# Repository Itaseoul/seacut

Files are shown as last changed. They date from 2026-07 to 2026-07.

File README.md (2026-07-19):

# SEA:CUT Drifter / Friendly Floatee

Open-source, non-profit river-to-sea litter drifter. A low-cost GPS + cellular float you release into a river, track from anywhere, and recover. It maps how floating trash travels from source to sea, so communities know where to place booms and cleanups.

Built by 사단법인 이타서울 / GAA and contributors. Inspired by the open-hardware movement (Precious Plastic, RepRap, OpenMetBuoy).

License: firmware MIT · hardware CERN-OHL-S (reciprocal) · docs CC BY-SA 4.0 (ShareAlike) · **data CC BY 4.0** (permissive, so pooled observations combine and cite freely). Design/doc improvements stay open; data stays freely reusable. See [LICENSE-docs.md](LICENSE-docs.md). OSHWA certification: planned.

한국어는 아래 [한국어](#한국어) 참조.

---

## What it does

Wake on a timer, get a GPS fix, POST one small JSON ping over the cellular network, sleep. The device sends a single coordinate; a server assembles the track. No user-built gateway is required, the mobile network is the infrastructure.

```
[drifter] --GPS fix--> --cellular (LTE) POST--> [ingest server] --> [public map / open data]
   sleep <-------------------------------------------- 200 OK
```

This is cellular (LTE), not satellite. Coverage is river, estuary, and near-coast where mobile networks reach. Open-sea tracking would need a separate satellite backhaul and is out of scope for this build.

### Where this fits (and what it is not)

This is the **upstream measurement layer**, not an interceptor. It does not remove trash and makes no ocean-scale claim. Big open-ocean interception projects (e.g. The Ocean Cleanup) act at the mouth and in the gyres; this drifter works **before** that — at the sub-river, source side — to answer *where does floating litter actually concentrate, and where should a boom or a cleanup go?* It is complementary to those projects, not a replacement for them. Its output is an **effort/path signal and a citable trajectory**, not a pollution flux, total, or a learned-AI prediction. Treat every buoyancy, power, and drift number here as an **estimate until bench + field measurement**; this repo is a reference design, and field validation plus a DOI-deposited dataset are pending. The shortest honest path from blueprint to validated project — bench gates, one small release, a citable deposit — is [docs/VALIDATION_CAMPAIGN.md](docs/VALIDATION_CAMPAIGN.md).

## The four rules (they travel with the design)

Open-source hardware spreads on a few strong universal rules plus local adaptation, not on the absence of caveats.

1. Recover what you release. A device left in the water is the very problem we fight. Design for recovery, track it, go get it.
2. Safe power, no toxics. Protected Li-ion, no charging below 0 C or cooking above 45 C, contain a cell failure, non-metallic housing.
3. Do no harm to the water or its users. Smooth non-entangling shapes, avoid protected areas and seasons, tell nearby water users.
4. Own your deployment, follow your local rules. See [docs/DEPLOY_responsibly.md](docs/DEPLOY_responsibly.md).

## Choose your tier

| | Tier 0 Phone-in-a-Bottle | Tier 1 Cellular Bottle (default) | Tier 2 Reusable Robust |
|---|---|---|---|
| Brain | reused smartphone + GPSLogger | ESP32 cellular board | ESP32 cellular board |
| Housing | upcycled PET bottle + dry bag | upcycled PET bottle | bolt-sealed IP case |
| Approx cost | USD 5–35 | USD 50–70 | USD 90–130 |
| Best for | first pipeline test, any budget | the default upcycled float | long / cold / repeated campaigns |

Full parts list: [hardware/BOM.md](hardware/BOM.md). Reference board is the LILYGO T-A7670G R2 with onboard L76K GNSS (cellular LTE Cat.1 bis + separate GPS chip). Pick the A7670 band variant for your region.

**Tier 1.5 (solar-assisted, long-dwell estuary)** — wrap-around thin-film cells extend reporting life for units that linger in-coverage for weeks; no extra printed part. ★Solar extends power, not coverage (open sea still needs satellite). See [hardware/TIER1_5_SOLAR_DRIFTER.md](hardware/TIER1_5_SOLAR_DRIFTER.md).

## 3D printed parts (parametric, OpenSCAD)

The housing is an upcycled bottle, so only three small printed inserts are needed. Sources are parametric OpenSCAD, so you measure your own bottle and edit one file.

- `hardware/cad/electronics_bracket.scad` holds the board and cell, self-locating in the bottle
- `hardware/cad/ballast_keel.scad` carries lead-free weight low for self-righting
- `hardware/cad/recovery_loop.scad` a smooth closed loop for pole/net recovery

Each ships as `.scad` (editable source) and `.stl` (print + GitHub renders it in 3D); export `.3mf` for slicers. (OpenSCAD is mesh-based, so no true STEP — see [hardware/cad/README.md](hardware/cad/README.md); the foam template exports `.dxf`.) Preview: `hardware/cad/assembly.png`.

## Firmware

[firmware/](firmware/) — ESP32 + A7670 + L76K, single ping per wake. Library lewisxhe/TinyGSM-fork + TinyGPSPlus. Default 30-minute interval.

## Data

[data/schema.md](data/schema.md) — ping and track schema (FF-ID v1.1), CC BY. Run your own ingest server or POST to the shared community map. Standards interop: [docs/DATA_STANDARDS_CROSSWALK.md](docs/DATA_STANDARDS_CROSSWALK.md) maps FF-ID onto CF-NetCDF (trajectory), OGC SensorThings, and EMODnet Physics — a drifter track is a trajectory, **not** a GBIF/Darwin Core occurrence — with a zero-dependency exporter ([data/export_standards.py](data/export_standards.py)).

## Contribute

Build a unit, release and recover it in your river, POST trajectories, add your river and your locale notes. Fork, improve, translate. Open a pull request.

---

## 한국어

하천에서 바다로 가는 쓰레기의 길목을 재는 오픈소스 비영리 드리프터. 강에 띄우고 어디서나 추적하다 회수하는 저비용 GPS + 셀룰러 부유체다. 인증받은 완제품을 배포하지 않는다. 당신이 만들고, 배포를 당신이 책임지고, 지역 규정을 따른다.

동작: 타이머로 깨어나 GPS fix, 셀룰러(LTE)로 ping 하나 POST, 잔다. 서버가 궤적을 조립한다. 게이트웨이 불필요. 이 스택은 셀룰러이지 위성이 아니다. 커버 범위는 이동통신망이 닿는 하천·하구·근연안이다.

네 가지 규칙: (1) 회수한다 (2) 안전 전원·무독성 (3) 물·이용자·야생동물 무해 (4) 네 배포는 네가 책임·지역 규정 확인. 상세 [docs/DEPLOY_responsibly.md](docs/DEPLOY_responsibly.md).

티어: Tier 0 폰+페트병(USD 5–35) / Tier 1 셀룰러+페트병(USD 50–70, 기본) / Tier 2 재사용 견고(USD 90–130). 부품표 [hardware/BOM.md](hardware/BOM.md). 기준 보드 LILYGO T-A7670G R2(온보드 L76K).

3D: 하우징이 폐페트병이라 프린트 부품은 3개(브래킷·밸러스트 킬·회수 고리)뿐. 파라메트릭 OpenSCAD라 병 규격만 바꾸면 된다. 전력·신뢰성 상세는 [hardware/ELECTRONICS_POWER.md](hardware/ELECTRONICS_POWER.md)·[hardware/RELIABILITY.md](hardware/RELIABILITY.md). 이 리포는 레퍼런스 설계이며 현장 검증(대량 방류 실증)은 준비 중이다.

전체 글로벌 가이드: [docs/OPEN_HARDWARE_BOM_global_ko.md](docs/OPEN_HARDWARE_BOM_global_ko.md).

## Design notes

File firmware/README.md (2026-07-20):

# Firmware

ESP32 + A7670 (LTE Cat.1 bis) + L76K GNSS. **FF-ID schema v1.1** ([data/schema.md](../data/schema.md)).

Wake on a timer → **GPS fix first** (so an observation is kept even with no coverage) → append to an RTC store-and-forward buffer with a monotonic `seq` → modem on → network → POST buffered records oldest-first → deep sleep. The device sends points; the server assembles the track and never trusts arrival order (it orders by `ts_fix`/`seq`).

Reference firmware: [`drifter_a7670_cat1/drifter_a7670_cat1.ino`](drifter_a7670_cat1/drifter_a7670_cat1.ino) (MIT).

## v1.1 payload (what each ping carries)

```json
{"device_id":"ff-kr-bs-u0001","site_id":"nakdong-hakjang","seq":1487,
 "lat":35.105600,"lon":128.943100,"batt":4.02,
 "sample_interval_s":1800,"fix_quality":1.4,"gnss_source":"l76k",
 "ts_fix":"2026-07-10T09:00:00Z","ts":"2026-07-10T09:00:00Z"}
```

- `seq` — monotonic per-device counter. Survives deep sleep (RTC memory) **and** power loss (NVS). The server dedups and detects gaps by `seq`.
- `ts_fix` — the GPS UTC time of the fix (the observation time). Legacy `ts` is sent with the same value for older ingest servers (schema 1.0→1.1 mapping).
- `sample_interval_s` — declared nominal cadence (required by the schema for mixed-cadence weighting).
- `fix_quality` — HDOP from the L76K (omitted when invalid); `gnss_source:"l76k"`.
- **Store-and-forward**: up to 16 records buffer in RTC memory across sleep cycles; a cellular dead zone does not lose observations. Power loss drops the buffer (documented tradeoff) but never reuses a `seq`.

## Toolchain

- Arduino IDE, ESP32 Arduino core 3.0.x, board "ESP32 Dev Module"
- Libraries: **lewisxhe/TinyGSM-fork** (required; stock TinyGSM lacks the A7670 macro — uninstall stock), TinyGPSPlus, ArduinoHttpClient. `Preferences` ships with the core.

## Configure

- `DEVICE_ID` — pair it with the unit metadata directory `unit_id` (schema §3).
- `APN` for your SIM (Soracom `soracom.io` user/pass `sora`; 1NCE `iot.1nce.net`; KT MVNO `lte.ktfwing.com`; SKT MVNO `lte.sktelecom.com`). Global IoT SIMs roam on KT/SKT only — no LG U+.
- `SERVER_HOST` / `SERVER_PATH` — bench with the bundled `ingest_server.py` (`BENCH_HTTP 1`), then promote to HTTPS (`BENCH_HTTP 0`).
- `SLEEP_MINUTES` — see [hardware/ELECTRONICS_POWER.md](../hardware/ELECTRONICS_POWER.md) for the honest endurance table (all figures estimates pending bench measurement).

## Gotchas

- GPS is the separate L76K chip on its own UART (NMEA via TinyGPSPlus), not the modem's AT GNSS.
- Test with the 18650 installed. USB-only power browns out on the ~2 A transmit peak and looks like a modem fault.
- The v1.1 flow order (GPS → modem) differs from the original bench-validated v1.0 order (modem → GPS). Primitives are unchanged, but **re-run the bench sequence before deploying a fleet** (honesty: no improvement claims before measurement).
- Start with plain HTTP, promote to HTTPS after the pipeline works end to end.

## Security & supply chain

Two hard requirements before any **real** deployment. Both are honest gaps in the reference build today — documented here rather than silently assumed fixed.

**1. TLS is encrypted but not yet authenticated.** In production mode (`BENCH_HTTP 0`) the firmware POSTs over HTTPS/443 with `TinyGsmClientSecure`. But on the A76xx the secure client **does not verify the server certificate unless you configure a CA certificate and enable server authentication** — so out of the box it is open to a man-in-the-middle (a hostile cell/roaming network could impersonate the server and read/alter observations). To close it:

- Obtain the server's CA/root certificate (PEM) — e.g. the Let's Encrypt / ISRG Root for `openc.caresea.kr`.
- Before the first `client.connect(...)`, set it and require verification, then **verify hostname** matches: `client.setCACert(PROD_CA_PEM);` plus the fork's SSL auth-mode / SNI configuration (`AT+CSSLCFG` "authmode" = verify server, "sni"/"servername" = the host). The reference `.ino` marks the exact call site with a `TLS-AUTH` comment and a commented hook.
- **Verify on hardware.** Per this repo's ethic (no improvement claims before measurement), do not treat TLS auth as working until you have watched a build *reject* a wrong/self-signed cert on the bench. A cert that never expires-checks is not authentication.

**2. Pin the modem library to a commit.** The build requires **lewisxhe/TinyGSM-fork** (stock `vshymanskyy/TinyGSM` lacks the `A7670` macro). "Use the fork" is a supply-chain risk if it means "whatever HEAD is today." For a fleet build, **install a pinned commit**, not a moving branch:

```
git clone https://github.com/lewisxhe/TinyGSM ~/Arduino/libraries/TinyGSM-fork
cd ~/Arduino/libraries/TinyGSM-fork && git checkout <COMMIT_SHA_YOU_VERIFIED>
```

Record the SHA you bench-verified next to your build (Arduino Library Manager cannot pin, so a production build must use a manually checked-out commit). Re-verify after any bump. Same discipline for TinyGPSPlus and ArduinoHttpClient versions.

Bench mode (`BENCH_HTTP 1`) is **plaintext HTTP over an ngrok tcp tunnel** — correct for a bench loop, never for real observations. Do not collect real data in bench mode.

## Bench re-verification checklist (v1.1, after the adversarial-review fixes)

1. **GPS power gate**: with `BENCH_HTTP 1`, confirm NMEA bytes arrive **before** the modem PWRKEY runs (serial shows a fix, or on failure `NMEA chars=` > 0).
   - ★**Schematic-confirmed** (docs/구멍_해결_2026-07-11.md, hole A2): the L76K VCC sits on the **V3V rail gated by GPIO12 (BOARD_POWERON) OR USB VBUS** — it does **not** depend on modem power-on. `getFix()` already raises `BOARD_POWERON` HIGH first, so GPS-first is expected to work. The old "move `modemPowerOn()` earlier" fallback is therefore **not** needed if `BOARD_POWERON` is HIGH.
   - ★**Verify on battery only** (USB disconnected): with USB, VBUS keeps V3V alive regardless of GPIO12, masking the gate. If `chars=0` on battery, probe V3V (TF-card VDD pad / PX header pin 16): it should read 0 V at GPIO12 LOW and 3.3 V at HIGH.
2. **Full cycle**: fix → buffer → POST 200 → deep sleep → wake, `seq` +1 each wake. Then kill coverage (unscrew LTE antenna) for 2–3 cycles and confirm the buffer flushes in one batch on recovery.
3. **HTTPS build**: `BENCH_HTTP 0` compiles under `TINY_GSM_MODEM_A76XXSSL` and POSTs over 443 (the modem class changes — re-verify attach; check the SSL client's CA-validation default).
4. **Sleep current**: measure before/after the GPIO-hold fix and update [hardware/ELECTRONICS_POWER.md](../hardware/ELECTRONICS_POWER.md) estimates with measured values.

> ★**First attach is the hardest step — instrument it or lose days.** A cold unit (no cached network) takes a while to register, and a silent failure looks identical whether the cause is a loose antenna, the wrong band, a roaming rejection, or a SIM that was never activated. Before you trust attach: enable `#define TINY_GSM_DEBUG Serial` (AT echo), and log `getSignalQuality()` (CSQ), `getRegistrationStatus()`, `getOperator()`, `getModemInfo()` around the attach; give the **first** attach **120–180 s** (a 60 s `waitForNetwork` is too short for a cold roam); and on failure retry 1–2× within the same wake before deep-sleeping. Global IoT SIMs attach on **KT/SKT only** — confirm the operator you actually landed on, not the one you expected.

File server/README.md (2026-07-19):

# Ingest server — 60-second quickstart

`ingest_server.py` is the reference ingest endpoint: a single file, **no dependencies** (Python 3
standard library only). It receives one small JSON ping per device wake, assigns the citation
`obs_id` + provenance, assembles the track, and serves a public map / open data — the
`[drifter] → [ingest server] → [public map / open data]` pipeline from the [README](../README.md).

This closes the reproducibility gate: cloning the public repo now gives you the server, so
`device → server → map` runs end-to-end without hunting for a file.

## Run it

```bash
python3 server/ingest_server.py 8770 0.0.0.0        # port 8770, all interfaces
# → logs "FF-ID schema v1.1"
```

Drive-run without a device (curl):

```bash
# a v1.1 ping (see data/schema.md §1)
curl -X POST http://localhost:8770/api/ping \
  -H 'Content-Type: application/json' \
  -d '{"device_id":"river-001","site_id":"nakdong-hakjang","seq":1,"lat":35.10560,"lon":128.94310,"batt":4.02,"ts_fix":"2026-07-10T09:00:00Z","sample_interval_s":900,"fix_quality":1.4,"gnss_source":"l76k"}'
# → {"ok":true, ...}   ; re-POST same seq → {"dup":true}
curl http://localhost:8770/api/live.geojson                 # assembled track
```

## Exposing it to a cellular device (★ the device is on LTE, not Wi-Fi)

The board reaches the internet over the carrier network, so a LAN/private IP (192.168.x.x) is
**unreachable** (carrier NAT). Expose the server publicly:

- `ngrok tcp 8770` → use the issued `host:port` as the firmware `SERVER_HOST`/`PORT`
  (`ngrok http` serves TLS and won't accept the plaintext bench client — see firmware header), OR
- router port-forward 8770 + a public IP.

## Data / license

Observations follow [data/schema.md](../data/schema.md) (FF-ID v1.1). Data is **CC BY 4.0**; run your
own server or POST to a shared community endpoint — same schema, so the data is interoperable.
Schema non-compliance = not included in the shared dataset (a gate, not enforcement).

> Reference implementation. Harden before production: TLS with a pinned CA on the device side
> (see firmware header), per-operator API-key write-auth, rate limiting, and the server-side physical
> plausibility / dedup checks described in DIY_DIVERSITY §5.2.

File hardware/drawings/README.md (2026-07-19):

# Drawings

Dimensioned assembly drawings (PDF) and 2D cut files (DXF) go here.

- `*.pdf` — dimensioned assembly / exploded views for makers who build by hand
- `*.dxf` — 2D profiles for laser cutting or CNC (if you make a non-bottle housing)

Generate from the CAD sources:

```
# 2D projection to DXF from an OpenSCAD part (add a projection() view, then)
openscad --export-format=dxf -o part.dxf part_2d.scad
```

For dimensioned PDF drawings: the CAD is OpenSCAD (mesh-based CSG), so there is **no true STEP** to import ([../cad/README.md](../cad/README.md) → "About STEP"). Either import the STL/3MF into FreeCAD (mesh, lossy) and dimension it in the TechDraw workbench, or annotate the assembly render directly. Keep the editable `.scad` source alongside any PDF (OSHWA prefers editable originals over output-only formats).

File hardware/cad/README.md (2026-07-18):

# CAD — full real-size assembly (parametric OpenSCAD)

The housing is an upcycled PET bottle. Three printed inserts + one cut part (foam collar) + real-size mockups of everything else, so the **complete Tier-1 drifter exists as a real-dimension 3D assembly**. All parametric: open `params.scad`, set your measured bottle inner diameter and board/cell sizes, and everything updates.

## Open CAD — three layers

1. **Web viewer** (rotate · explode slider · per-part toggle): https://uploads.caresea.kr/seacut/hardware/index.html
2. **GitHub STL** — every `.stl` below renders in 3D in the browser.
3. **OpenSCAD parametric source** — the editable master (OSHWA prefers editable originals).

## Files

| File | Part | Role |
|---|---|---|
| `params.scad` | shared parameters | ★measure your bottle and edit here first |
| `electronics_bracket.scad` | electronics bracket (print, ≤60% infill) | holds board + 18650, self-locates on the bottle wall |
| `ballast_keel.scad` | ballast keel (print) | lead-free weight at the belly for self-righting |
| `recovery_loop.scad` | recovery loop (print) | smooth closed loop, wildlife-safe |
| `foam_collar.scad` | **foam collar ×2 (CUT master, not printed)** | flooded-reserve buoyancy — 2 collars ≈ 160 cm³ closed-cell EVA keep a flooded unit afloat (RELIABILITY §4). Cut/stack EVA sheet to this shape |
| `foam_collar_2d.scad` → `foam_collar_template.svg` / `.dxf` | **1:1 cut template** | true-mm SVG (print at 100 %) and DXF (laser/CNC). Printable A4 page with calibration ruler + layer table: https://uploads.caresea.kr/seacut/hardware/foam_template.html |
| `mockups.scad` | bottle · LILYGO board · 18650 · ballast · antennas | real-size visual stand-ins for the assembly |
| `assembly.scad` | **full assembly** | everything in deployed position; `-D explode=1` for the exploded view |
| `export_part.scad` | per-part STL export | assembled-coordinate STLs for the web viewer |
| `asm_*.stl` | 10 assembled-position parts | what the web viewer and GitHub render |
| `assembly.png` / `assembly_exploded.png` | renders | assembled / exploded |

## Edit and export

Install OpenSCAD (free, open source). Edit `params.scad`, then:

```
# one printed part (STL prints, and GitHub renders STL in-browser)
openscad -o electronics_bracket.stl electronics_bracket.scad
# full assembly previews
openscad -o assembly.png --autocenter --viewall --imgsize=1400,1000 assembly.scad
openscad -o assembly_exploded.png -D explode=1 --autocenter --viewall --imgsize=1400,1000 assembly.scad
# all viewer STLs (assembled coordinates)
for p in bracket keel loop foam_a foam_b board antennas cell ballast bottle; do
  openscad -o asm_$p.stl -D "part=\"$p\"" export_part.scad; done
# 3MF (mesh interchange for slicers/CAD)
openscad -o electronics_bracket.3mf electronics_bracket.scad
```

**About STEP**: OpenSCAD is mesh-based CSG and **cannot export true (BREP) STEP** — an earlier note here claiming `--export-format=step` was wrong. If you need STEP, import the STL/3MF into FreeCAD and convert (mesh-based, lossy) or remodel; the **OpenSCAD source stays the editable master** (which is what OSHWA asks for).

The committed `.stl` files are reference geometry. Measure your bottle and parts, adjust `params.scad`, re-export. Mockup dimensions (bottle profile, board, cell) are visual estimates — replace with your measured values.

Units are millimeters. Print in a durable, non-toxic filament (PETG recommended for water contact), **infill ≤60%** (`print_infill_max` — keeps the 160 cm³ foam spec valid; solid prints need ~175 cm³). No supports needed if oriented flat.

**Solar variant (Tier 1.5)** — [`solar_variant.scad`](solar_variant.scad) + `assembly.scad` with `-D solar_enable=1` (render [`assembly_solar.png`](assembly_solar.png)). The [long-dwell solar drifter](../TIER1_5_SOLAR_DRIFTER.md) adds **no new printed part** — flexible thin-film cells wrap the body and the charge controller/NTC/vent are COTS. `solar_variant.scad` is a **viz-only mock (exports no printable STL)**. CAD-side gates: (1) keep the ballast keel low and **ballast at 40 g unchanged** — never trade it down to offset solar mass (raises CG, kills T7 self-right); (2) re-cut the foam collar with the **density-aware +6.7 cm³/10 g** (panel ρ≈1.64, *not* the ballast 7.9→11.7); (3) the RF window is a top +Z sector kept film-free — ★the local→global axis map is easy to invert, so **render and confirm the film-free wedge sits over the antennas** (done: `assembly_solar.png`); (4) cells must be **non-metal RF-transparent substrate** (B5), verified by T6 with cells installed. No STL change.

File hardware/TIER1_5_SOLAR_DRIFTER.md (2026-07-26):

# hardware/TIER1_5_SOLAR_DRIFTER.md — 솔라 보조 드리프터 (장기 잔류·회수 보험 변형)

> **한 줄 요약**: Tier 1 셀룰러 보틀에 **원통을 감싸는 박막 솔라 셀**을 더해, 하구 장기 잔류(주+) 임무에서 배터리 단독으론 죽어버릴 유닛의 보고 수명을 늘린다. ★**솔라는 전력을 늘리지 커버리지를 늘리지 않는다** — 셀룰러 범위 안 장기 잔류(하구 체류·연안 배회·좌초)에서만 값을 하고, 외해 이탈은 여전히 위성(Class 3)의 영역이다. 단기 회수형(Tier 1)엔 그대로 솔라 없음.
>
> ★이 문서는 도메인 전문가 5인(기구·전력·부력·소재·오픈HW) + 적대 검증 + 통합의 결과이며, 3대 교정(저온 컷오프 전 모드 필수·비금속 기재 하드게이트·신규 프린트 0)이 반영됐다.

정본 의존: [ELECTRONICS_POWER](ELECTRONICS_POWER.md) · [FLOAT_STANDARD](FLOAT_STANDARD.md) · [RELIABILITY](RELIABILITY.md) · [VERIFIED_BUILD_TEST](VERIFIED_BUILD_TEST.md) · [BOM](BOM.md) · [DIY_DIVERSITY](../docs/DIY_DIVERSITY.md) · CAD [cad/params.scad](cad/params.scad)·[cad/solar_variant.scad](cad/solar_variant.scad).

---

## 0. 언제 쓰나 (그리고 언제 안 쓰나)

**쓴다 — 장기 잔류 임무:**
- 하구 체류가 주~달 단위인 곳. 한강하구 실증(사례연구 Case 6): 쓰레기 **~12%만 외해, 대부분 하구 1달+ 잔류**. 배터리 단독(60분 핑 ~2주)으론 잔류가 끝나기 전에 죽어 **유닛을 잃는다**(죽은 유닛 = 회수 불가). 솔라가 보고를 이어가면 추적 + 회수가 산다.
- **회수 지연·표착 대비 보험**: 예정보다 오래 표류/좌초해도 계속 보고 → 결국 회수.

**안 쓴다:**
- **단기 회수형(며칠 내 회수)** — 배터리로 충분, 솔라는 무게·CG·열 비용만 → **Tier 1 유지**(CAD `solar_enable=0`). ELECTRONICS_POWER §3 "단기 회수형엔 순손해"는 이 경우에 여전히 유효.
- **외해 추적** — ★솔라는 **전력** 문제만 푼다. 유닛이 셀룰러 범위를 벗어나면(외해 ~11km) 배터리가 가득해도 **침묵**한다. 외해는 위성(Class 3)이지 솔라가 아니다.

### ★0-1. 정직 경계 — "전력 ≠ 커버리지"

"30일 표류인데 배터리로는 못 찾는다"는 **범위 안 장기 잔류**에선 솔라가 푼다(계속 보고 → 회수). 그러나 **범위 밖 이탈**은 전력을 아무리 늘려도 못 찾는다(신호 자체가 없음). 솔라를 "외해에서도 찾게 해주는 것"으로 오해하지 말 것.

---

## 1. 구조 변경 — 자기복원 vs 패널 충돌을 구조로 해소

1. **원통 감싸는 박막 셀 + ★비금속 RF투과 기재 하드게이트** — 평판 1장 대신 유연 박막을 병 몸통에 빙 두른다. ★**자기복원체는 떠 있는 자세가 고정**(윗면이 늘 하늘·배는 늘 물속이라 어두움)이라 '아무 면이나 교대 수광'이 아니다 — 감는 실익은 **굽은 윗면 호 전체가 해의 일주·요잉(제자리 회전)·동요에도 계속 수광**하고, 기울어도 일부 면이 유지되며, **분산 저질량이라 CG를 안 올린다**(딱딱한 평판을 위에 얹으면 CG↑=자기복원 악화)는 것. **물속 아랫면은 발전 못 하므로 유효 수확 ≈ 물 밖 윗부분만**(과대계산 금지, G5 실측). **기재는 a-Si(ETFE 전면) 또는 Cd-free CIGS(폴리이미드)만.** ★**스테인리스 기재 CIGS·CdTe·페로브스카이트 금지**(RF 차폐 + 독성 + 곡률 파단) — 이는 소프트 권고가 아니라 **하드 게이트**(FLOAT_STANDARD B5 "안테나를 금속으로 감싸지 않음"). CAD `solar_cell_substrate="metal"`이면 빌드 중단. 비금속이라도 TCO·그리드 감쇠가 남으므로 최종 관문은 **T6(소크 후 RF 재취득)를 셀 장착 상태로** 통과.
2. **자기복원 보존(절대 조건)** — 밸러스트는 그대로 **배 아래 40 g 불변**. ★솔라 무게를 상쇄하려 밸러스트를 줄이지 말 것(가장 흔한 자기복원 킬러). 박막은 가볍고 몸통에 분산돼 CG를 거의 안 올린다. 안테나는 최상단, 셀은 그 아래 몸통을 감싸며 **위쪽 120° 섹터(+Z)는 필름-프리**(안테나·회수고리 노출, [assembly_solar.png](cad/assembly_solar.png) 렌더로 검증됨).
3. **★충전 경로 — 기본 외부 저Iq 선형 차저 → 배터리 단자** — ★T-A7670G R2에는 **문서화된 솔라 포트가 없다**(문서화된 경로는 USB-5V→내장 리튬 충전 IC, 모뎀은 VBAT 직결). 자매보드 T-SIM7000G의 CN3065 솔라 JST를 이 보드에 있다고 가정하지 말고 **실제 리비전 회로도를 벤치에서 확인**. ★**단서(2026-07-27)**: LILYGO 공식 `utilities.h`의 T-A7670 정의에 **`BOARD_SOLAR_ADC_PIN 36`이 존재**한다 — 솔라 입력 전압을 읽는 핀이 정의돼 있다는 것은 **보드에 솔라 입력 패드가 있을 가능성**을 시사한다(사실이면 외부 충전 회로가 간단해질 수 있음). **ADC 정의가 곧 충전 회로의 존재를 증명하지는 않으므로**(전압만 재는 핀일 수 있음) 실물 회로도·패드로 확인 전에는 설계로 굳히지 말 것. [GPS_MODULE_WIRING §7-5](GPS_MODULE_WIRING.md) 참조. 기본 = 외부 COTS 저Iq 선형 차저(CN3065급, Iq≈1.5µA)를 **배터리 단자**에 붙이고 기존 브래킷 리브에 지퍼타이. 온보드 IC 직결은 **소면적 한정 예외**(벅/부스트로 패널을 5.0~5.2 V 고정 + 외부 NTC 동반). 청정·여름 고수확 사이트만 MPPT(CN3791급) 옵션.
4. **★저온 충전 컷오프 — 전 모드 필수(하드웨어 래치)** — LILYGO 내장 충전기엔 셀 캔 NTC가 없어 0℃ 이하 충전을 못 막는다. **모든 모드(온보드 포함)에 독립 하드웨어 저온 컷오프**(10k B3435 NTC를 18650 캔에 에폭시 본딩; TS핀 내장 차저 또는 나노파워 비교기, **펌웨어 의존 금지**)로 <0℃ 충전을 하드 차단. JEITA: <0℃ 정지·0~10℃ 테이퍼·>45℃ 정지.
   - **구현 2경로 (★참조회로는 벤치 검증 후 확정 — 미검증 회로를 정답으로 박지 않는다)**:
     - **(a) 1차 = 차저 TS핀** — 10k B3435 NTC를 차저(CN3065급) **TS핀↔GND**에 분압으로 물려 차저가 자체 온도차단. ★**함정: 값싼 CN3065 브레이크아웃은 TS핀이 고정저항으로 죽어 있어** 온도차단이 아예 안 걸린다 → **TEMP/TS핀이 실제 노출·활성인 회로도 버전**을 구매 전 확인.
     - **(b) 백업 = 나노파워 비교기 래치** — 저Iq 비교기(예: TLV3691급, Iq≈0.15µA) + 기준전압(예: TLVH431급)으로 NTC 분압을 문턱과 비교해 **충전 인에이블(또는 패널 라인)을 하드 차단**. 차저 TS핀을 못 믿을 때의 독립 안전장치.
   - **문턱**: 충전 정지 **+2℃**(센서 오차·열지연 여유), 재개는 이력(hysteresis)으로 +5℃ 이상. 고온 정지 **45℃**(여름·다낭). 두 경로 다 **펌웨어 비의존 하드웨어 래치**이며 기능은 **G6(§4)**로 실측 검증한다.
5. **벤트(Gore-Tex ePTFE 접착 패치)** — 셀 흡열분 + 밀폐 가압 관리(F2). ★**프린트 보스가 아니라** 캡에 붙이는 접착 패치(조립 §4·RELIABILITY F4/B8).
6. **★부력 재계산(밀도인지 계수)** — 추가 질량에 대해 폼을 키우되, **밸러스트 전용 계수 +11.7 cm³/10g이 아니라 저밀도 솔라용 +6.7 cm³/10g**(패널 ρ_eff≈1.64). §5 참조.
7. **배터리 유지** — 보호 18650(또는 2셀 버퍼). 솔라는 **대체가 아니라 연장**(트리클).

★**신규 프린트 부품 = 0.** 랩=접착 필름, 컨트롤러/NTC/벤트=COTS, 폼=재단 EVA, bracket/keel/loop/foam_collar 전부 재사용(커널 #6).

---

## 2. 전력 원칙 — 솔라는 설계 입력이 아니라 보너스

- **배터리는 예정 잔류 기간을 단독으로 버티게 사이징**한다. 솔라는 그 너머의 **마진**(보험). 솔라 믿고 배터리를 줄이지 않는다.
- 수확은 보수적으로 — 뒹굴 방향·하천 탁도·수막·생물부착·야간으로 명목값의 일부만.
- ★**연장일수(예: "N일")를 인용하지 않는다.** 벤치 G5 전에는 **손익분기 H\*와 연장계수 1/(1−H/D)까지만** 표기(H=일 수확, D=일 소비). "자기지속(self-sustaining)" 마케팅 금지. **<0℃면 저온 컷오프로 H→0** → 겨울 장기 잔류는 솔라가 아니라 대용량 배터리/저독성 1차전지로.

---

## 3. BOM 델타 (Tier 1 대비 추가 · 신규 프린트 0)

| 부품 | 스펙 | ~비용(USD) | 신규 프린트 |
|---|---|---|---|
| 박막 셀 | 유연 **a-Si(ETFE 전면)** 또는 **Cd-free CIGS(폴리이미드)**, 5~6V, 최소곡률반경 ≤46mm. ★**비금속 RF투과 기재만**(스테인리스 CIGS·CdTe·페로브스카이트 금지). 전면재 ETFE(PET 아님 — UV 황변·박리) | 8~15 | 없음(랩) |
| 접착 스택 | 3M VHB 마린 + 실란 PET 프라이머 + UV안정 열수축 슬리브 + 리드 엣지 부틸/에폭시 씰 | 3~6 | 없음 |
| 충전 컨트롤러 | **기본: COTS 저Iq 선형 차저**(CN3065급, TS핀 NTC). 옵션: MPPT(CN3791급, 청정·여름만). **배터리 단자에, 기존 브래킷에 지퍼타이** | 0~10 | 없음 |
| NTC(저온 컷오프) | 10kΩ B3435, 18650 캔에 에폭시 본딩. **전 모드 필수·하드웨어 래치** | 0.5 | 없음 |
| 격리 다이오드 | 쇼트키/이상다이오드(패널 역류 차단) | 0.5 | 없음 |
| 벤트 | **Gore-Tex ePTFE 접착 패치**(캡) — 프린트 보스 아님 | 2~4 | 없음 |
| 추가 폼 | EVA 재단, **밀도인지 +6.7 cm³/10g**(≈+26 cm³ @ 39g) | ~1 | 없음(재단) |
| (선택) 2nd 18650 | 버퍼 — ★**매칭 셀 + 격리 다이오드/밸런싱**, 벨리 배치, cell_holder 재사용. 아니면 단일 대용량 보호셀 선호 | 8~11 | 없음 |

**합계 ≈ +$15~30. 신규 프린트 부품: 0.**

---

## 4. 벤치·검증 (Tier 1 게이트에 더함)

- **G5 · 솔라 수확(특성화·손익분기)** — 완성 상태(필름·컨트롤러 배터리단자 배선·NTC 캔본딩·폼 `foam_vol_solar`)에서: ①정적 최적 자세 기준전류 ②**요잉·동요 시간평균**(자기복원체는 **상면 자세가 고정**이나 요잉으로 수광 호가 이동·**배는 항상 어두움**) ③모의 탁도/수막 ④노화(a-Si는 초기 10~30% 안정화 후) ⑤일주 적분 → **수확 H(mAh/day)** ⑥**야간 컨트롤러 정지전류 실측**(mA급 MPPT는 야간 손실!) — Iq가 일평균 수확을 넘으면 순손해 → 선형/야간게이트. ⑦목표 핑의 **실측 소비 D**와 비교. **손익분기 H\*≈132 mAh/day**(ELECTRONICS_POWER §1.5, 60분·모뎀오프). **연장계수 1/(1−H/D)만**(H<D일 때), **일수 인용 금지**. H가 순증이 아니면 "보험 트리클"로 라벨하고 배터리가 잔류를 독립 감당.
- **T7 · 셀 장착 자기복원**(= VERIFIED_BUILD_TEST **T4를 솔라 페이로드 장착 상태로 재시험**) — 필름+컨트롤러+NTC+배선 다 장착, 폼 `foam_vol_solar`, **밸러스트 40g 불변**. 뒤집어 투하 → 5회 자동복원 ≤5초·최종 안테나 수면 위. 5~10초=밸러스트 **위치**(질량 아님) 재튜닝, 실패=방류 금지.
- **T7이 강제하는 재통과 3종**: **T1**(밀봉 침지 **30분**, Δm≤0.5g / >2g FAIL — 정본 VERIFIED_BUILD_TEST)를 **배선 그로밋 관통 장착 상태로**(새 누수점) · **F2/T2**(72h 침수부양)를 `foam_vol_solar`로(예비부력비 ≥1.20) · **T6**(소크 후 GPS≤5분·LTE≤10분)를 **셀 장착 상태로**(major B 강제 — 랩이 안테나를 안 가림을 증명, 금속 기재는 여기서 탈락).
- **G6 · 저온/고온 충전 컷오프 기능시험 (발화 직결·필수)** — 완성 배선 상태에서: **① 셀을 아이스팩/냉동고로 <0℃까지 낮추고 충전전류가 0 A로 떨어지는지 실측**(안 떨어지면 저온 래치 미작동 = **방류 금지·발화 위험**). **② 셀을 >45℃로 데워 충전전류 0 확인**(여름·다낭 고온). ③ 문턱 근처(±2℃)에서 이력으로 채터링(껐다켰다) 없는지 확인. ★**펌웨어가 아니라 하드웨어가 끊는지**를 본다 — 펌웨어를 강제 정지시켜도 충전전류는 0이어야 한다. §1-4의 (a)/(b) 어느 경로든 이 시험을 통과해야 한다.
- **G7 · 솔라 랩 담금 생존 (장기 잔류 필수)** — ★T1(하우징 밀봉)·G5(수확량)와 **별개**로, **필름 자체가 몇 주 침지를 견디나**를 본다(가장자리·리드로 물 스며 부식하는지). 완성 유닛(밀봉·랩·**가장자리/리드 밀봉**)을 **예정 잔류 기간(또는 대표값, 예: 2주)만큼 물에 담근 뒤**: **① 필름이 여전히 발전하는지**(담금 전 대비 출력 유지·급감 여부) **② 가장자리·리드로 물 침투 없는지**(필름 배면 결로/변색·박리·출력 급감) **③ 부식 흔적**(하구=기수는 더 가혹). 출력 급감·침투=밀봉 재시공 후 재시험. ★**'생활방수 표기'만 믿지 말 것** — 몇 주 연속 침지는 비·물튀김보다 훨씬 가혹하니 **담가 봐야 안다.** 민물 < 기수(하구 장기잔류는 특히).

**방류 게이트**: G5 특성화 + **G6(저온/고온 컷오프)** + **G7(솔라 랩 담금 생존)** + T7 + T1 + F2 + T6 전부 통과, 아니면 방류 금지.

---

## 5. 부력 / CG 재계산 (밀도인지)

기준(RELIABILITY §3~4): M_dry 199g · V_solid 101.9cm³ · 폼 160cm³ → 침수 예비부력비 **1.275 PASS**.

★**계수 정정**: 솔라 하드웨어 ρ_eff≈1.64(밸러스트 7.9 아님). §4 정합식 `ΔV=(1.25·Δm − Δm/ρ)/(1−1.25·ρ_foam)=/0.95` → **6.7 cm³/10g**(리포의 11.7은 ~74% 과대). 폼은 **벤치 실측 Δm에 게이트**:

| Δm(벤치) | 최소 폼 | 채택 | 침수 예비부력비 | 칼라 두께(×2) |
|---|---|---|---|---|
| 20g(하한) | 168 | 172 | 1.265 | ~29mm |
| **39g(nominal)** | **181** | **185** | **1.266** | **~31mm** |
| 45g(상한) | 185 | 189 | 1.265 | ~31.5mm |

(★표 채택값은 완전식 기준 — CAD 증분식 `foam_vol_solar`는 39g에서 186cm³로 근소 상회, 둘 다 벤치 대체.) ★**폼을 160에 두지 말 것** — 39g에서 1.17로 떨어져 1.20 하한 FAIL. ★**밸러스트는 40g 불변**(벨리); 솔라 무게 상쇄로 감량 절대 금지(CB−CG 마진 잠식). 2nd셀 시 Δm≈+95g → 폼 ≈230cm³·벨리 배치·매칭+격리다이오드·F2/T7 재통과. *모든 CG/예비부력비는 추정 위의 추정 — T7+F2+T1이 대체.*

---

## 6. 3D / CAD (오픈소스 — 편집 가능한 정본)

- **[cad/params.scad](cad/params.scad)** — 솔라 파라미터 블록(전부 추정 → 벤치 교체). `solar_enable`·밀도인지 폼·RF 창·컨트롤러 위치·NTC. ★**비금속 기재 게이트는 `assert()`로 코드에서 강제**(`solar_cell_substrate="metal"`이면 빌드 abort — 산문 주장이 아니라 실제 차단). 밀도인지 폼은 `foam_collar(collar_t_solar)`로 지오메트리에 연결돼 **렌더·STL이 실제로 커진다**(base 27→~31mm).
- **[cad/solar_variant.scad](cad/solar_variant.scad)** — 랩·컨트롤러·벤트 **viz 전용 모듈**(★프린트 STL 미출력 — 신규 부품 0). 랩의 로컬→글로벌 축 매핑(local −x → global +Z)이 뒤집히기 쉬워 **assembly 렌더로 RF 창이 +Z에 떨어지는지 확인**하게 설계.
- **[cad/assembly_solar.png](cad/assembly_solar.png)** — `openscad -D solar_enable=1`로 렌더. ★**RF 창이 +Z(안테나 쪽)에 정확히 떨어짐을 렌더로 검증 완료**(필름은 아래 240°만, 위 120°는 필름-프리).
- 렌더: `openscad -o assembly_solar.png -D solar_enable=1 --autocenter --viewall --imgsize=1500,1050 assembly.scad`. **실병·실안테나 위치를 실측해 params 갱신** 후 재렌더(현 좌표는 mockups.scad 추정치).

---

## 7. 정직 각주

- **솔라 = 전력, 커버리지 아님.** 커버리지 밖은 위성(Class 3). 이 변형은 **외해 추적을 주장하지 않는다**(커널 #4).
- **자기복원 절대.** T7(=T4 셀 장착, 밸러스트 40g 불변, 폼 `foam_vol_solar`)은 하드 방류 게이트. 실패=안테나 익수=통신·측위 동시 사망(커널 #1).
- **단기 회수형엔 솔라 없음.** `solar_enable=0`; ELECTRONICS_POWER §3 "단기 순손해" 불변(커널 #5). 솔라는 마진이지 배터리를 줄이는 설계 입력이 아니다.
- **셀 안전.** 보호 18650·하드웨어 NTC/JEITA(<0℃ 충전 차단, 전 모드)·Gore-Tex 벤트(커널 #2).
- **회수-우선 불변.** 수명↑=회수확률↑이지 방치 허가 아님(count-in=count-out). 솔라 화학물질은 유실 시 환경부하가 커 **회수가 더 중요**.
- **신규 프린트 0.** 랩=접착 필름·컨트롤러/NTC/벤트=COTS·폼=재단 EVA·기존 프린트 4종 재사용(커널 #6).
- **모든 수치는 추정 → 벤치가 대체.** 수확·폼·Δm(20~45g 발산)·CG·예비부력비·연장계수. **연장일수·"자기지속"·수확상수 금지.** "T7"은 T4 재시험 라벨(신규 테스트 아님). 이 설계는 전문가 **4/5 커버리지**(오픈HW 렌즈 1개 실패) + 적대 검증 통과 — 재현성 세부는 후속 QA 라운드에서 보완.

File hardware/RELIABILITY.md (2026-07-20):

> **한 줄 요약**: 밀봉 1L PET 병은 배수 ~1000cm³로 총질량(추정 ~199–207g) 대비 예비부력비 약 4.8배라 정상 시 절대 안 가라앉지만, 진짜 실패모드인 밀봉 누수 침수(순부력 −97gf) 를 폐쇄셀 폼 160cm³(6.4g) 로 역전시켜 "침수돼도 뜨는" 회수-우선 설계를 성립시킨다.

## 0. 기준·규약 (정직 가드)

- **유체 기준**: 담수 하천 ρ_water = 1.0 g/cm³. 부력 = 배수부피(cm³) × 1.0 = 배수질량(g). 힘 단위는 **gf(gram-force)** 로 표기해 질량(g)과 직접 비교. (하구 기수 ρ≈1.005–1.02는 부력을 약간 **키우므로** 담수 기준이 보수적 = 안전측.)
- **지표 정의 통일(★필수)**:
  - **예비부력비(reserve buoyancy ratio) = 부력 ÷ 질량 = V_disp / M**. 확립사실의 "예비부력 4~6배"가 이 정의다.
  - **초과부력비(excess buoyancy ratio) = 순부력 ÷ 질량 = (V_disp − M) / M**. 별도 지표로만 병기하며 예비부력비와 혼용 금지.
- 모든 수치는 **추정(estimate)** 이며 계산식 동봉. 현장 실측 아님.
- 통신은 **셀룰러(LTE Cat.1 bis)** — 위성 아님. 위치·상태는 **물리 계산/정수역학** 결과이지 학습형 예측·정확도%가 아님. 운영 대원칙은 **회수-우선**(기기를 하천에 버리지 않음).

---

## 1. 질량 예산 표 (추정) — 단일 기준값

**밸러스트는 튜닝 변수**이나, 전 문서 정합을 위해 **기준값 = 밸러스트 40g → M_dry 199g / M_wet 207g** 을 채택한다. (밸러스트 60g은 §5의 '자기복원 튜닝 상한 시나리오'로만 부기.)

| 부품 | 추정 질량(g) | 근거/범위 |
|---|---|---|
| LILYGO T-A7670G R2 (ESP32+A7670G+L76K) | 20 | BOM 추정 18–22g 중앙값 |
| 보호회로 18650 1셀 | 48 | 추정 45–50g |
| PET 1L 빈 병(하우징) | 28 | 추정 25–30g |
| 프린트 인서트(브래킷+킬+회수고리, PLA) | 35 | ★STL 실측: 3부품 solid 부피 **56.9cm³**(브래킷 40.4+킬 9.95+고리 6.57) → 인필 40%≈28g·60%≈42g·100%≈71g. 채택 35g ≈ 50% 인필(실측으로 타당성 확인) |
| 밸러스트(스테인리스, 55×22 포켓) | 40 | ★튜닝 변수(기준값) |
| 실런트+그로밋 | 8 | 추정 5–10g |
| uFL 안테나 2종(LTE+GNSS) | 8 | 추정 5–10g |
| 배선·테이프·QR라벨·파라코드 | 12 | 추정 |
| **건조 합계 M_dry** | **199 g** | Σ |

**최악 흡수수분 여유**: PLA 흡습 ~0.5–1%(0.2–0.4g) + 라벨·파라코드·테이프 젖음 ~5–7g → **+8g** → **젖은 상태 M_wet ≈ 207 g**. 설계 판정은 M_wet 기준.

---

## 2. 밀봉 정상 상태 — 예비부력비 & 건현

밀봉된 1L 병 배수부피 **V_disp ≈ 1000 cm³**.

- **부력** F_b = 1000 cm³ × 1.0 = **1000 gf**
- **예비부력비 = V_disp / M = 1000 / 207 ≈ 4.83×** (M_dry 199g 기준 5.03×) — 확립사실 4~6배 범위 내.
- (참고) **초과부력비 = (1000 − 207)/207 ≈ 3.83×** — 별도 지표, 예비부력비와 구분.

> ★**부유 자세 = 수평(정본).** 이 유닛은 벨리 밸러스트로 **수평으로 떠서 자기복원**한다([SELF_RIGHTING.md](SELF_RIGHTING.md)·`cad/assembly.scad`, 건현 ~73mm). 아래의 '수직 자세' 건현(~124mm)은 **보수적 경계 추정(레거시)**이지 운용 자세가 아니다 — 두 값 다 30mm 게이트는 통과하나, 안테나 여유·질량 기준은 **수평 정본**으로 본다.

**건현(freeboard) 개략** — (보수적 경계) 수직(안테나 위) 자세 가정, 내경 Ø90mm(params `bottle_id=90`) → 단면적 A = π(4.5)² = **63.6 cm²**, 유효 병 길이 L ≈ 1000/63.6 ≈ **15.7 cm**.
- 흘수 d = 207/63.6 ≈ **3.3 cm**, **건현 ≈ 15.7 − 3.3 ≈ 12.4 cm** (추정).
- ★실제 1L 병은 넥·테이퍼로 균일 원통이 아니므로 건현은 근사(추정). 높은 건현 = 큰 풍압면적 + 세장형 수직체 = 전도 경향 → 자기복원 킬 필수(§5).

---

## 3. ★침수(flooded) 상태 — 순부력 (폼 없음)

밀봉 누수로 병 공기가 사라지면 **1000cm³ 배수는 소멸**하고, 각 고형부품은 **자기 재질부피만큼만** 물을 밀어낸다. 순부력 = Σ(재질 배수부피) − Σ(질량).

| 부품 | 질량(g) | 밀도(g/cm³) | 배수부피(cm³) | 순부력(gf) |
|---|---|---|---|---|
| PET 병 플라스틱 | 28 | 1.38 | 20.3 | −7.7 |
| 보드(FR4+부품, 틈새 물참) | 20 | ~1.9 유효 | 10.5 | −9.5 |
| 18650(밀봉 스틸캔, 전부피 배수) | 48 | — | 18.5¹ | −29.5 |
| 밸러스트 스테인리스 | 40 | 7.9 | 5.1 | −34.9 |
| 프린트 PLA | 35 | 1.24 | 28.2 | −6.8 |
| 안테나(플라+금속) | 8 | ~2.0 | 4.0 | −4.0 |
| 실런트 실리콘 | 8 | 1.10 | 7.3 | −0.7 |
| 배선·기타 | 12 | ~1.5 | 8.0 | −4.0 |
| **합계** | **199** | | **101.9** | **−97.1 gf** |

¹ 18650 부피 = π(0.93)²×6.8 = 18.5 cm³ (Ø18.6×68mm, params `cell_d=18.6 / cell_l=68`).

**침수 순부력 ≈ −97 gf (추정, 음수) → 침몰 확정.** 이것이 진짜 실패모드다: 배터리(−29.5)와 밸러스트(−34.9)가 적자의 66%. **폐쇄셀 폼으로 이 −97gf를 상쇄+여유 확보해야 "침수돼도 뜨는" 설계 성립.**

---

## 4. ★폐쇄셀 폼 1차 부력 사이징 (정본 방법 = 1.25 예비부력비 기준식)

**폼 가정**: 폐쇄셀 EVA/EPE, ρ_foam ≈ **0.04 g/cm³** (범위 0.03–0.05). 폐쇄셀이라 침수돼도 흡수 없이 전부피 배수. 폼 순부력 계수 = (1.0 − 0.04) = **0.96 gf/cm³**.

**정본 사이징식** (고형부품의 자체 배수 Σ_solid를 반드시 포함 — 이를 무시하면 과대 사이징):
```
[ Σ고형배수 V_solid + V_foam ] ≥ reserve_target × [ M_dry + ρ_foam·V_foam ]
```
**+25% (reserve_target = 1.25) 대입** (M_dry=199, V_solid=101.9):
```
101.9 + V_foam ≥ 1.25 × (199 + 0.04·V_foam)
101.9 + V_foam ≥ 248.75 + 0.05·V_foam
0.95·V_foam ≥ 146.85
V_foam ≥ 154.6 cm³
```
**+20% (1.20)**: V_foam ≥ 142 cm³. **+30% (1.30)**: V_foam ≥ 167 cm³.

→ **설계 채택 V_foam = 160 cm³** (흡수수분 여유 포함, +27.5% 수준).

> **★STL 실측 반영(인필 규칙):** 프린트 실측 부피 56.9cm³를 부력식에 되먹이면 필요 폼 = **인필 40%→152cm³ · 60%→158cm³ · 100%(solid)→172cm³**. 따라서 **채택 160cm³는 인필 ≤60%에서 유효(PASS)**. solid(100%)로 뽑으면 **폼을 175cm³로 상향**하거나 인필을 낮춘다. **설계 규칙: 프린트 인필 ≤60% 권장**(가볍고 폼 160 성립). ★PLA(ρ1.24)가 물과 근중립이라 인필을 바꿔도 침수 순부력은 −96~−104gf로 강건(실측이 확인).
- 폼 질량 = 0.04×160 = **6.4 g** (총질량 199→205.4g)
- 침수 배수 = 101.9+160 = 261.9 cm³ → **침수 순부력 = 261.9 − 205.4 = +56.5 gf**, **침수 예비부력비 = 261.9/205.4 = 1.275 (+27.5% 초과부력) → PASS**.

> **각주(안전율 상향 옵션, 정본 아님)**: 고형부품의 자체 배수(82~102cm³)를 전혀 신뢰하지 않고 "고형질량 전체를 폼만으로 상쇄"하는 보수적 방법을 쓰면 ~245cm³가 나온다. 이는 방법론적으로 덜 정밀(고형 자체배수 무시)하며 **정본은 위 155cm³→채택 160cm³**다. 245cm³는 극한 안전율이 필요한 특수 캠페인에서만 옵션으로 상향.

**폼 형상 옵션** — ★폼은 **params.scad에 없는 Tier 1 BOM 비항목·신설 부품**이다(아래 §6 참조). 치수는 신설 설계값:
- **환형 칼라(collar)**: 외경 ~Ø86mm(병 내경 90 안에 여유 끼움), 내부 페이로드 채널 70×40mm 컷아웃. 단면적 = π(4.3)² − (7.0×4.0) = 58.1 − 28.0 = **30.1 cm²** → 높이 h = 160/30.1 ≈ **53 mm**(상·하 2×27mm 분할 권장).
- **단순 블록**: EVA 80×40×50mm ≈ 160 cm³, 병 곡률에 맞춰 모서리 라운드.

**재활용 옵션(정직한 트레이드오프)**:
- **폐부표/폐EVA 스크랩**: 1차 부력재 재사용 가능(Sea Cut 폐부표 재활용 서사와 시너지). ★사용 이력 폼은 셀 파손·물먹음으로 밀도 상승 위험 → **로트별 24h 침수 후 질량증가 <5% 검수 필수**.
- **재활용 HDPE(Precious Plastic)**: ρ≈0.95 → 순부력 0.05 gf/cm³뿐(거의 중립). **부력재 부적합**, 구조 브래킷/킬/회수고리 등 **구조부품**으로만 활용이 정직. 부력은 반드시 저밀도 폐쇄셀 폼이 담당.

---

## 5. 자기복원(self-righting) & 밸러스트-폼 트레이드오프

**원리**: 부양 시 무게중심 CG가 부력중심 CB보다 **아래**여야 복원모멘트 발생(안테나 위로 세움). 밸러스트 스테인리스 30–50g을 **병 최하부(킬 포켓, params `ballast_l=55 / ballast_w=22`)** 에 집중, 폼 칼라는 상부 2/3에 배치.

**★밸러스트-폼 트레이드오프 유도식(정정)**: 1.25 예비부력비를 유지하려면 밸러스트 Δm(g) 추가 시 필요한 추가 폼:
```
ΔV_foam = ( reserve_target·Δm − Δm/ρ_ballast ) / ( 1 − reserve_target·ρ_foam )
```
- **Δm = +10g, ρ_ballast=7.9, ρ_foam=0.04, R=1.25**: ΔV_foam = (1.25×10 − 10/7.9) / (1 − 1.25×0.04) = (12.5 − 1.27) / 0.95 ≈ **+11.8 cm³**.
- 즉 밸러스트 +10g마다 **폼 약 +11.8cm³** 필요(명시적 트레이드오프). **권장 밸러스트 = 40g**, 여유가 필요하면 35g로 낮추면 폼 여유↑. (★분모는 예비부력비 R을 유지하는 정확식 `1−R·ρ_foam`; 저밀도 솔라 하드웨어는 [TIER1_5 §5](TIER1_5_SOLAR_DRIFTER.md)의 밀도인지 +6.7.)

**CG/CB 개략(추정)**: 밸러스트 40g@바닥(y≈1cm), 배터리 48g@중하(y≈5cm), 보드 20g@중(y≈8cm), 폼6.4g+안테나8g@상(y≈13cm) → 가중 CG ≈ 5.1cm. 침수(고흘수) 상태에선 CB 상승으로 수직 복원 유리. **최소 건현 권장 ≥ 30mm**(밀봉 정상 흘수 기준). ★밀봉이 온전하면 월파해도 침수 아님 — 폼은 **밀봉 실패 시 생존** 보장용(2차 안전망).

---

## 6. 파라메트릭 CAD 반영안 (params.scad — 실존 파일)

★`hardware/cad/params.scad` 는 **실재**하며 다음 값이 이미 정의됨(단일 진실원천):
`bottle_id=90`, `wall=2.4`, `clr=0.4`, `board_l/w/h=68/34/12`, `cell_d/l=18.6/68`, `ballast_l/w=55/22`.
이 값들을 근거로 아래 부력·폼 변수를 **추가**한다. ★폼 칼라 치수(Ø86·채널70×40)는 params에 없던 **신설 부품**이므로 새 변수로 도입한다.

```openscad
// --- flotation & hydrostatics (NEW; estimates; verify per build) ---
foam_vol             = 160;   // cm^3 closed-cell foam (flooded reserve, non-BOM new part)
foam_density         = 0.04;  // g/cm^3 EVA/EPE estimate (0.03–0.05)
reserve_ratio_target = 1.25;  // flooded excess: (disp/mass) >= this  (PASS>=1.20)
sealed_reserve_min   = 3.0;   // sealed: 1000cm3/mass >= this (design ~4.83)
freeboard_min        = 30;    // mm minimum calm-water freeboard
ballast_mass_g       = 40;    // ★tuning var; +10g needs +~11.8cm^3 foam
// --- foam collar geometry (NEW part, not derived from bottle wall) ---
foam_od     = 86;             // mm, fit inside bottle_id=90 with margin
foam_bore_l = board_l + 2;    // 70 mm payload channel (board_l=68)
foam_bore_w = board_w + 6;    // 40 mm (board_w=34)
foam_area   = PI*pow(foam_od/2,2)/100 - (foam_bore_l*foam_bore_w)/100; // ~30.1 cm^2
foam_collar_h = foam_vol / foam_area;   // ~53 mm; split 2×27
```
※ 실제 폼은 3D프린트가 아니라 **EVA 시트 절단/열성형**으로 제작 — .scad는 절단 지그·치수 산출용 마스터.

---

## 7. 실패모드 & 완화책 (확장 — 침수 외 모드 포함)

| # | 실패모드 | 물리 | 완화책(1줄) |
|---|---|---|---|
| F1 | ★밀봉 누수 침수 | 공기 상실 → 순부력 −97gf → 침몰 | 폐쇄셀 폼 160cm³(§4) + 24h 소크시험(VERIFIED_BUILD T1) |
| F2 | **셀 열폭주·벤팅** | 여름 직사광·과충전 시 18650 벤팅 → **밀봉 병 내부 가압·파열·발화** | 압력균등화 그로밋/벤트 경로 확보, NTC/JEITA 충전보호, 직사광 차광, 셀 홀더 봉쇄 |
| F3 | **생물부착(biofouling)** | 장기 계류(60분·40일)로 조류·따개비 부착 → 질량↑ → 예비부력 잠식·표류계수 변화 | 계류형은 주기적 회수·세척, 장기 운용 예비부력 여유 상향, 표류 재보정 |
| F4 | **무누수 내부결로** | 누수 없이 주야 온도차로 병 내부 수분이 전자부 위 응축 → 전원/RF 고장 | 봉인 전 건조제(실리카겔) 투입·결로 확인, Gore-Tex 통기벤트로 압력평형 |
| F5 | **동결·결빙 팽창** | 겨울 하천 결빙 시 침투부 물 동결팽창 → 밀봉/그로밋 균열 | 결빙 예보 시 방류 회피, 그로밋 재질 저온 검증, F1 소크 재시험 |
| F6 | **자세 경사 시 안테나 수몰** | 세장형 수직체는 복원성 낮아(tender) 옆으로 뜸 → 안테나 수몰 → GPS·LTE 동시 두절 | 하부 밸러스트 집중·저중심화(§5), T4 자기복원 통과, 복원팔 정량은 현장 확인 |
| F7 | **PET·폼 장기 열화** | PET UV취화·크리프로 캡 실 이완, EVA/EPE UV·마모로 수주 후 흡수 개시(폐쇄셀 '흡수 없음' 가정 붕괴) | 단기 회수-우선 운용 원칙, 재사용 로트 재검수, UV 노출 최소화 |

---

## 8. 설계 판정 기준 (pass/fail, 추정)

| 항목 | 기준 | 계산값 | 판정 |
|---|---|---|---|
| 밀봉 예비부력비(부력/질량) | ≥ 3.0 (목표~5) | 4.83× | **PASS** |
| 정상 건현 | ≥ 30 mm | ~124 mm | **PASS** |
| 침수 순부력(폼 없음) | (실패모드 확인) | −97 gf | 침몰=FAIL(예상) |
| **침수 예비부력비(폼 160cm³)** | **≥ 1.20 (목표 1.25)** | **1.275** | **PASS** |
| 필요 폼 부피(정본 1.25식) | — | ≥155cm³ → 채택 160 | **PASS** |
| 자기복원 | CG < CB(침수시) | CG~5.1cm, 하부밸러스트 | **PASS(조건부)** |
| 폼 흡수 검수 | 24h 침수 질량↑ <5% | 로트검사 | 검수 필요 |

**결론(추정)**: 밀봉 정상 시 예비부력비 ~4.8배로 압도적, 진짜 위험인 **밀봉 누수 침수(−97gf)** 를 **폐쇄셀 폼 160cm³(6.4g)** 로 +27.5% 초과부력까지 역전 → "침수돼도 뜨는" 회수-우선 설계 성립.

---
> **정직 가드 각주**: 담수(ρ=1.0) 기준·셀룰러(LTE, 위성 아님)·물리 정수역학 계산(학습형 예측·정확도% 아님)·회수-우선(기기 안 버림)·현장 실측 날조 금지. 모든 수치는 **추정(estimate)** 이며 계산식과 함께 제시. 예비부력비=부력/질량, 초과부력비=순부력/질량으로 정의를 분리 표기.

---

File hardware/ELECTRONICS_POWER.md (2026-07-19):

# hardware/ELECTRONICS_POWER.md — 전원 예산 · 전원 하드웨어 (Friendly Floaty / SEA:CUT)

**한 줄 요약:** Class 1 하천 회수형(우리 Tier1 BOM = LILYGO T-A7670G R2 + 보호 18650)의 전원 예산은 **핑 간격과 "모뎀 등록유지 vs 모뎀 오프"라는 설계 분기**에 지배되며, 상온 기준 5분 ≈ 1.6~4일 · 15분 ≈ 3.5~7.4일 · 60분 ≈ 6.3~19일 수준으로 **추정**된다(전부 벤치 실측으로 확정 필요). 통신은 **셀룰러(위성 아님)**, 운영 대원칙은 **회수-우선(count-in = count-out)**이다.

> ★**클래스는 제품 3종이 아니라 성숙 사다리다.** **Class 1 = 검증기**(설계를 손에 쥐고 밀봉·자기복원·전력·attach를 증명하는 프로토 단계 · 현재 · ChangeX 범위) → **Class 2 / Tier 1.5 = 운용 미션기**(커버리지 내 장기 잔류 · source-to-sea 데이터 · 태양광이 **이 클래스의 표준장비**) → **Class 3 = 프론티어**(외해 · 위성 · 유실허용 · 다른 기기). 아래 §1~§3 예산은 **검증기(Class 1) 기준**이며, '태양광 순손해' 판정도 **Class 1 한정**이다 — 미션기에선 배터리 단독으로 회수 전에 죽어 태양광이 표준이 된다.

---

## 0. 정직 기준 (먼저 고정)

- **모든 전력 수치는 추정(estimate)이며 넓은 범위 + "벤치 실측 필요"다.** 전류 프로파일러/파워 애널라이저로 실기기 실측하기 전까지 어떤 수치도 확정으로 인용하지 않는다. 특히 **슬립 전류·GPS 콜드픽스 에너지·LTE attach 평균전류**는 편차가 커서 사이클당 소비의 지배 변수이자 최대 불확실 요인이다.
- **통신은 셀룰러(LTE Cat.1 bis, A7670G)다. 위성 아님.** 셀 커버리지가 없는 외해에서는 이 기기가 작동하지 않으며, 그것은 **Class 3(다른 기기 클래스)**의 영역이다. ChangeX(부산 소하천 PoC) 제출·예산·설계에는 **Class 1만** 등장한다.
- 위치·상태는 **물리 계산·측위**이지 학습형 AI 예측(정확도%)이 아니다.
- 배터리는 **보호회로 포함 18650**, 가용 용량 **~2500 mAh @ 공칭 3.7V (≈9.25 Wh)**로 **가정**한다. 보호 PCB 소비·자기방전·저온/컷오프 여유 때문에 데이터시트 정격보다 보수적으로 잡은 값이며, **실측으로 교체해야 한다.**
- 태양광은 **Class 1 검증기(단기 회수형)엔 대체로 순손해**다(질량·과열·부력·복원성 4축 악화, §3). ★단 이는 **검증 단계 한정 판정**이다. **운용 미션기(Class 2 / Tier 1.5, 커버리지 내 장기 잔류)에선 배터리 단독이 회수 전에 죽으므로 태양광이 표준장비**가 된다([TIER1_5](TIER1_5_SOLAR_DRIFTER.md)). '태양광=exotic 옵션'은 Class 1에만 참이지 제품 전체의 기본값이 아니다. 진짜 필수 문턱(무인+주 이상+회수 불가+커버리지 밖)은 Class 3다.

---

## 1. Class 1 전원 예산 (기본 · ChangeX · 우리 BOM)

### 1.1 전제 · 가용 용량

| 항목 | 값(추정) | 근거 / 주의 |
|---|---|---|
| 가용 용량 `C_usable` | ~2500 mAh @ 3.7V (≈9.25 Wh) | 보호 18650. 보호PCB·자기방전·컷오프 여유 반영. 데이터시트 정격보다 보수적. **실측 필요** |
| 전원 급전 | **VBAT 직결 우선** | 모뎀은 VBAT 직결이 기본. ESP/센서용 3.3V LDO/부스트 경로가 있으면 ~10~15% 변환 오버헤드가 붙으므로 **직결 여부를 회로에서 1줄로 확정**할 것 |

### 1.2 계산식

```
사이클수/일        N        = 1440 / 핑간격(분)
사이클당 소비      E_cycle  = E_gps + E_esp + E_lte            [mAh]
일 소비            D        = (I_sleep[mA] × 24) + (N × E_cycle) [mAh/일]
가동일수(상온)     Days     = C_usable / D        (C_usable = 2500 mAh)
가동일수(냉수)     Days_cold = Days × k_cold       (k_cold = 0.70 ~ 0.90)
```

### 1.3 구성 요소 추정 범위 (★넓게, 벤치 실측 필요)

- **① 슬립 전류 `I_sleep`** — 이 보드는 초저전력 설계가 **아니다.** 온보드 LDO 정지전류 + 전원 LED + 모뎀 슬립 잔류가 합산된다. **슬립은 독립 변수가 아니라 모뎀 정책과 커플링**된다(§1.4).
  - 모뎀 **등록유지** idle: 실측 **5~15 mA**가 흔함
  - 모뎀 **완전 오프** + LED/불필요 LDO 차단: **1~3 mA** 목표 (★현 스톡 보드엔 없는 하드웨어 개조 전제)
- **② GPS fix** — L76K. 콜드 30~90s @ ~30~40 mA면 **~1.5 mAh/사이클**, 웜/핫이면 수 초로 **~0.2 mAh**. **핑 간격에 의존**(§1.7).
- **③ ESP 활성** — 처리·대기 ~40~80 mA, 10~30s → **0.1~0.5 mAh/사이클**.
- **④ LTE attach + POST** — **순간피크 ~2A**(짧은 버스트), 평균 100~300 mA. **재attach(콜드 등록) 여부에 크게 좌우** → 등록유지면 낮고, 모뎀 오프면 매 웨이크 콜드 재attach로 커진다.

### 1.4 두 개의 정합 시나리오 (슬립 ↔ attach 커플링 명문화)

**낙관/중앙/비관을 뒤섞으면 자기모순이 난다**(최저 슬립=모뎀오프인데 최저 attach=등록유지를 동시에 못 씀). 그래서 **모뎀 정책 두 분기**로 예산을 재구성한다:

| 분기 | 슬립 `I_sleep` | 사이클당 `E_cycle` | 유리한 구간 |
|---|---|---|---|
| **A — 모뎀 등록유지 (keep-alive)** | 높음 **8 mA** | 낮음 **1.5 mAh** (웜 attach·웜/핫 GPS) | **단주기**(사이클이 잦아 사이클당 비용이 지배) |
| **B — 모뎀 완전 오프 (power-cycle)** | 낮음 **2 mA** | 높음 **3.5 mAh** (콜드 재attach·콜드 GPS) | **장주기**(사이클이 드물어 슬립이 지배) |

> **핵심 물리:** 두 분기는 **핑 간격에서 교차**한다. 단주기(5~15분)는 A가, 장주기(60분)는 B가 유리하다. 어느 쪽이 정답인지는 배포 주기가 정한다 — 단일 "낙관치"는 존재하지 않는다.

### 1.5 가동일수 표 (상온, `C_usable` = 2500 mAh)

| 핑 간격 | N | **A: 등록유지** (슬립8mA·1.5mAh/cyc) | **B: 모뎀오프** (슬립2mA·3.5mAh/cyc) | 권장·상온 범위 |
|---|---|---|---|---|
| **5분** | 288 | 192+432=624 → **약 4.0일** | 48+1008=1056 → **약 2.4일** | **A** 권장 ≈ **4.0일** |
| **15분** | 96 | 192+144=336 → **약 7.4일** | 48+336=384 → **약 6.5일** | ≈ 교차점, **A** 근소우위 ≈ **7.4일** |
| **60분** | 24 | 192+36=228 → **약 11.0일** | 48+84=132 → **약 18.9일** | **B** 권장 ≈ **18.9일** |

**비관(worst) 하한** — 스톡 보드(전원 LED 상시 + 고 idle 등록) + 콜드 픽스·콜드 재attach가 겹칠 때: 슬립 12 mA · `E_cycle` 4.5 mAh 가정 →

| 핑 간격 | 계산 | 비관 하한 |
|---|---|---|
| 5분 | 288+1296=1584 → 2500/1584 | 약 **1.6일** |
| 15분 | 288+432=720 → 2500/720 | 약 **3.5일** |
| 60분 | 288+108=396 → 2500/396 | 약 **6.3일** |

**정직 범위(상온, 비관 하한~권장 상한):** 5분 ≈ **1.6~4.0일**, 15분 ≈ **3.5~7.4일**, 60분 ≈ **6.3~18.9일**.

> ★ **이전 초안의 "60분 최대 52일"은 폐기했다.** 그 값은 슬립 1 mA(전원 LED 제거 + 모뎀 완전 오프)라는 **현 BOM에 없는 하드웨어 개조**를 전제하고도, 모뎀 오프의 콜드 재attach 비용을 낮은 attach와 섞어 과대 산출한 수치였다. **스톡 보드 무개조 현실은 60분에서 대략 6~19일**이며, 공격적이지만 현실적인 저전력 개조(LED 제거·LDO 차단·슬립 최적화)를 다 해도 **~25일 상단**이 정직한 천장이다. 52일은 인용 금지.

### 1.6 냉수 보정 + 저온 펄스-컷오프 여유

겨울 하천/냉수(≈5~10℃)에서는 셀 **가용 용량이 대략 10~30% 감소**한다. 권장 상온 일수에 `k_cold = 0.70~0.90`을 곱한다:

| 핑 간격 | 권장(상온) | 냉수 보정 후 |
|---|---|---|
| 5분 | 4.0일 (A) | 약 **2.8~3.6일** |
| 15분 | 7.4일 (A) | 약 **5.2~6.7일** |
| 60분 | 18.9일 (B) | 약 **13.2~17.0일** |

> ★ **`k_cold`는 순수 용량 감소만 반영한다.** 저온에서는 셀 **내부저항↑ → LTE ~2A 펄스 시 전압 새그↑ → 보호 PCB 조기 컷오프**가 겹칠 수 있어, 실사용 가용치가 `k_cold` 하한(0.70) **아래로 더 떨어질 수 있다.** 이는 용량 derate와 **별개의 여유**로 다루고, 저온 배포 시 핑 간격을 늘려 마진을 확보한다.

### 1.7 GPS 픽스 상태의 핑간격 의존 (콜드 균일적용의 방향성·한계)

에페메리스 유효기간(~2~4h) 때문에 픽스 상태는 핑 간격에 의존한다: **단주기(5~15분)는 대부분 웜/핫 픽스(수 초)**, **장주기(수 시간+)는 콜드 픽스가 지배적**이다. 위 표는 편의상 보수적으로 콜드 쪽을 얹었으므로 **단주기 열은 보수(과대 소비) 방향, 장주기 열은 콜드 정합**이다. 콜드픽스 "지배"는 장주기에서 성립하는 조건부 명제이며, 단주기에서 콜드 1.5 mAh를 매 사이클 적용하는 것은 안전측 과대 추정임을 유의한다.

---

## 2. 미션/기기 클래스 매트릭스

| 항목 | **Class 1 하천 회수형** (기본·ChangeX·우리 BOM) | **Class 2 하구·연안** | **Class 3 외해 라그랑주** |
|---|---|---|---|
| 미션 | 도시 소하천 병목→표류 실측, 대시민/교육 | 하구·연안 표류 추적, 캐치포인트 유입 관측 | 외해 라그랑주 표류·해양물리 과학계기 |
| 기간 | 시간 ~ 며칠 | 며칠 ~ 주 | 주 ~ 개월 |
| 전원 | **보호 18650 단독, 회수해 재충전** | 큰 배터리(2~4셀/대용량) ± **소형 태양광** | **태양광+충전** 또는 **대용량 1차전지(비충전)** |
| 통신 | **셀룰러 (LTE Cat.1 bis)** | **셀룰러** (연안 커버리지 내) | **위성** (셀룰러 커버리지 없음). ★우리 BOM 아님 |
| 회수 | **회수-우선** (전량 회수·재충전) | 캐치포인트/드론/보트 회수 | **사실상 회수 불가** → 저영향 소재로 손실 최소화 |
| 소재/환경 | 재활용 PET 캡슐 + 폐쇄셀 폼, 담수 정수역학 | 기수(ρ≈1.005~1.02), 생물부착·염수부식 대응 | 저독성·저영향 소재(OpenMetBuoy/GDP식) |
| 우리 위치 | **검증기(현재·ChangeX 범위).** 손에 쥐고 증명하는 프로토 단계 | **운용 미션기(성숙 목표).** 장기 잔류·태양광 표준·source-to-sea 데이터 | **프론티어(다른 기기 클래스).** ChangeX와 절대 혼용 금지 |

**핵심 프레임 한 줄:** 태양광이 **표준장비**가 되는 순간은 **커버리지 내 장기 잔류(Class 2 / Tier 1.5)** — 배터리 단독이 회수 전에 죽는 지점 — 이고, **위성이 필수**가 되는 순간은 **무인 + 주 이상 + 회수 불가 + 커버리지 밖**이 겹치는 **Class 3**다. **Class 1(검증기)**은 사람이 회수해 재충전하므로 두 문턱 다 넘지 않는다 — 그래서 **검증 단계에선 태양광이 순손해**다. 운용의 무게중심이 장기 잔류로 이동하면 기본 클래스도 Class 2 / Tier 1.5로 이동한다.

**회수-우선의 클래스별 강도:** Class 1은 "버리지 않는다"가 절대 규칙(방류 대수 = 회수 대수 장부 대조), Class 2는 "회수 경로를 설계에 내장"하는 목표치, Class 3는 회수가 물리적으로 불가능하므로 규칙이 **"소재로 방어"(저독성·저영향·손실 최소화)**로 치환된다. **우리 BOM 기기(Class 1)와 ChangeX는 이 치환을 하지 않는다 — 언제나 전량 회수다.**

---

## 3. 태양광 옵션 스펙 (Tier-3)

태양광은 **Class 3(무인·주 이상·회수 불가)** 또는 Class 2의 장기 무인 변형에서만 검토한다. Class 1 단기 회수형엔 **대체로 순손해**다. 아래는 "굳이 켤 때"의 조건부 스펙이다.

> ★**장기 잔류 드리프터 변형(Tier 1.5)**: 커버리지 내에서 주+ 잔류하는 드리프터에 솔라를 얹는 별도 변형은 [TIER1_5_SOLAR_DRIFTER.md](TIER1_5_SOLAR_DRIFTER.md)에 있다(원통 셀로 자기복원 보존·저온컷오프·벤치 G5 수확 검증). 본 §3의 고정 Tier-3와 구분되며, **단기 회수형엔 여전히 순손해**라는 위 원칙은 그대로다. 솔라는 전력을 늘리지 커버리지를 늘리지 않는다.

### 3.1 켜기 전에 통과해야 할 문턱 (셋 다 성립해야 검토)

1. **무인** — 사람이 접근·회수해 재충전할 수 없다.
2. **주 이상** — 배터리 단독 예산(~2500 mAh)으로 못 버티는 기간이다.
3. **회수 불가** — 손실을 전제로 저영향 과학계기로 설계한다(회수-우선 포기 → Class 3 소재 기준으로 전환).

### 3.2 부품·설정 스펙 (옵션 채택 시)

| 요소 | 스펙 / 조건 | 정직한 트레이드오프 |
|---|---|---|
| 소형 패널 | 세장형 수직 캡슐 상부에 소면적. **자기복원 시 패널이 하향**할 수 있어 발전량 불안정. **하천 탁도·수막·이물로 효율 추가 저하** | 방향·오염 손실을 크게 잡아 보수적으로 산정 |
| 충전 컨트롤러 | MPPT/PWM + **저온 충전 컷오프(0℃ 이하 리튬 충전 금지, JEITA/NTC) 필수** | 컷오프 없으면 저온 충전으로 셀 열화·안전 문제 |
| 밀폐함 열관리 | 패널·흑체 흡열로 밀폐 병 내부 온도↑ → **F2(셀 열폭주·벤팅) 악화.** 차광·통기벤트(Gore-Tex)·압력균등화 필수 | 태양광이 오히려 최악 실패모드를 키운다 |
| 추가 질량 → 부력 | 패널·컨트롤러·배선 추가 질량 = **부력 재계산 필수.** RELIABILITY 정본식 `[Σ고형배수 + V_foam] ≥ 1.25 × (M_dry + ρ_foam·V_foam)`으로 폼 재사이징 | 질량 늘면 흘수↑·건현↓·자기복원 여유↓ |
| 자기복원 상호작용 | 패널을 상부에 두면 CG 상승 위험(CG < CB 유지 필요) → 하부 밸러스트 재튜닝 → 밸러스트↑ → 다시 폼↑ (연쇄 재계산) | CG 상승은 복원성 직접 잠식 |

> **부력 재보정 계수(참고, ★정본 의존):** RELIABILITY §5 밸러스트-폼 트레이드오프식에 따르면 질량 +Δm에 대해 **폼 약 +11.7 cm³/10g** 수준의 재보정이 필요하고, 폼 160 cm³ 기준 침수 예비부력비 **1.275(PASS, 목표 ≥1.25)**의 여유가 태양광 추가로 잠식된다. ★이 교차인용 수치는 본 문서 내에서 검증 불가하며 **RELIABILITY 정본의 실재·정합을 별도 확인**해야 한다. **패널은 밀도가 달라 계수는 실측으로 재산정**해야 한다. (★저밀도 랩 필름 변형(Tier 1.5)은 밀도인지 **+6.7 cm³/10g** — [TIER1_5 §5](TIER1_5_SOLAR_DRIFTER.md). 여기 11.7은 리지드 패널 프레임 등 고밀도 추가물에만 해당.)

### 3.3 태양광 대신 대용량 1차전지가 나은 때

**저온·저일사·고탁도**(겨울 하구, 흐린 계절, 탁수)에서는 태양광 회수 에너지가 불확실하다. 이때는 **대용량 비충전 1차전지**가 (a) 충전 컷오프·과열 리스크 없이 (b) 예측 가능한 에너지 예산을 준다. 단, 1차전지는 **회수 불가 시 환경 유실 부하**가 크므로 **저독성·저영향 셀 선정 + 손실 최소화**(Class 3 소재 원칙)를 전제로만 쓴다. 회수 가능한 시나리오면 애초에 Class 1(18650 재충전)이 정답이다.

**결론(정직):** 태양광은 "친환경적으로 보이는 기본값"이 아니다. Class 1에선 **질량·과열·부력·복원성 네 축을 모두 악화**시키는 순손해이고, **무인 + 주 이상 + 회수 불가** 세 문턱을 다 넘을 때만 켜는 Tier-3 옵션이다.

---

## 4. 전원 하드웨어 노트 (설계 필수)

- **2A 피크 대응(벌크캡/슈퍼캡):** 18650 단독으로 LTE 송신 피크(~2A)를 때리면 셀 내부저항 때문에 전압이 순간 강하해 모뎀 브라운아웃/리셋 위험. **모뎀 전원 레일에 벌크 커패시터(470~1000 µF 이상) + 슈퍼캡/대용량 세라믹 뱅크를 병렬**로 두어 피크를 흡수한다. **USB 5V 단독 급전 금지**(USB 전류제한·케이블 강하로 attach 시 리셋 유발).
- **★보호 PCB 과전류 트립(캐패시터만으론 불충분):** ~2A 버스트가 **저전류 보호보드의 OCP**를 건드리면 리셋 루프에 빠진다. **연속 3A+ 정격의 보호 PCB**를 반드시 선정할 것. 벌크캡·슈퍼캡은 순간 새그를 완화할 뿐 OCP 트립 자체를 막지 못한다.
- **냉수 = 이중 손해:** 용량↓ + 내부저항↑ → 저온에서 2A 피크 시 전압 강하가 더 심해진다(§1.6 펄스-컷오프 여유). 방수함 내부에 셀을 두어 자기발열을 살짝 활용하거나, 저온 배포 시 핑 간격을 늘려 마진을 확보한다.
- **★저온 회수-재충전 회전율(운용 각주):** 0℃ 미만에서는 **리튬 셀 충전 자체가 금지**(저온 충전 = 셀 열화·석출)다. 이는 런타임이 아니라 **회수 후 재충전 회전 주기**에 영향을 준다 — 겨울 현장 회수 셀은 상온 복귀 후 충전해야 하므로 **회전율이 떨어진다.** 여분 셀 풀을 확보해 방류-회수 사이클을 유지한다.
- **슬립 최적화가 장주기 시나리오의 관건:** 60분처럼 사이클이 드물면 **슬립 드레인이 전체 소비를 지배**한다(§1.4 분기 B). LED 제거·불필요 LDO 차단·모뎀 완전 오프(재attach 비용 감수) 여부가 6일↔19일을 가른다 → **슬립 전류를 최우선으로 실측**할 것.
- **전원 변환 경로 확정:** 모뎀 VBAT 직결이면 변환 손실은 무시 가능하다. 그러나 **ESP/센서용 3.3V LDO나 부스트 경로가 있으면 ~10~15% 오버헤드**가 붙는다. 회로에서 직결 여부를 명시하고, LDO 경로가 있으면 위 예산에 여유율을 반영한다.
- **기성 보드 / Tier-3 KiCad 경계:** Tier1은 **커스텀 PCB 없이 기성 LILYGO T-A7670G R2**를 그대로 쓴다(개조는 LED 제거·LDO 차단·전원 레일 캡 추가 수준). 커스텀 KiCad 설계는 **Tier-3(장기 무인·태양광 옵션) 전용**으로 미룬다 — Class 1 회수형은 기성 보드로 충분하며, 커스텀 보드는 검증 부담만 키운다.

---

## 정직가드 각주

1. **추정·벤치필요:** 본 문서의 모든 mAh·일수·전류·피크·계수는 **추정 범위**이며, 특히 **슬립 전류(§1.3·§1.4)·GPS 콜드픽스(§1.7)·LTE attach 평균전류·저온 펄스 컷오프(§1.6)**는 **실기기 벤치 실측으로 반드시 교체**해야 한다. 정밀 주장으로 인용 금지.
2. **셀룰러 = 비위성:** 우리 BOM 기기는 셀룰러(LTE Cat.1 bis)다. 위성이 필요한 것은 **Class 3(외해·다른 기기)**뿐이며, **ChangeX와 절대 혼용하지 않는다.**
3. **물리 계산 = 비학습:** 위치·상태는 정수역학·측위 계산이며 학습형 AI 예측(정확도%)이 아니다. 운영 대원칙은 **회수-우선(count-in = count-out)**.
4. **태양광 = Tier-3 옵션:** 태양광은 기본이 아니다. **무인 + 주 이상 + 회수 불가** 세 문턱을 동시에 넘는 Class 3에서만 켜며, Class 1에선 질량·과열·부력·복원성 네 축을 악화시키는 순손해다.
5. **교차인용 주의:** §3.2의 예비부력비 1.275·+11.7 cm³/10g·reserve 1.25는 **RELIABILITY 정본 의존** 수치로 본 문서 내 검증 불가 — 정본 실재·정합 여부를 별도 확인하고, 패널은 밀도가 달라 계수를 실측 재산정할 것.

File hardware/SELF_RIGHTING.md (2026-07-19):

# Self-righting — computed, not just claimed

The drifter must ride **antenna-up** or it goes deaf: a submerged antenna kills GPS and cellular
(FLOAT_STANDARD, Rule 2 of the four rules). The design achieves this with belly ballast. This page
turns "self-rights antenna-up" from an assertion into a number, with an explicit statement of what
the number does and does **not** prove.

Calculator: [cad/self_righting.py](cad/self_righting.py) (pure stdlib; defaults mirror `cad/params.scad`).

```
$ python3 hardware/cad/self_righting.py
  mass 153 g  ->  submerged 13%  waterline 16.6 mm  freeboard 73.4 mm
  KB 9.8  BM 35.2  ->  KM 45.0 mm (~= axis R=45, circular-section property)
  KG 33.9 mm  (must be < axis 45 for antenna-up)   ->  GM = R - KG = 11.1 mm
  righting arm GZ(phi) = GM*sin(phi):  10deg=1.9  30deg=5.6  45deg=7.9  60deg=9.6  90deg=11.1 mm
  VERDICT: PASS  (need GM>5 mm and KG<42 mm; antenna-up single-equilibrium confirmed only by tank test)
```

## The model

The float lies **horizontal** (schema calibration `form.attitude`), so this is **roll stability of a
partly submerged circular cylinder**, radius R = 45 mm (bottle_id 90). Standard hydrostatics:

- Displaced volume `V = mass / ρ_water`; solve the waterline height `h` so the submerged circular
  segment × body length equals V. At the ~153 g reference mass the bottle floats high (~13% submerged,
  73 mm freeboard) — it is buoyancy-rich, as intended (a sealed 1 L bottle has ~4.8× reserve).
- **KB** = centroid of the submerged area (numeric integration). **BM** = `I_waterplane / V`.
- **KG** = mass-weighted centroid of the component budget (ballast low, board/antenna high).
- **GM = KB + BM − KG** — the metacentric height. GM > 0 ⇒ initially stable in roll.

## The clean result (why a bottle is a good hull)

For a prismatic **circular** section the metacenter sits on the section **axis at any draft**:
`KM = KB + BM = R`. The calculator prints `KM 45.0 ≈ R 45` as a sanity check. Therefore

> **GM = R − KG**, and the large-angle righting arm is the pendulum `GZ(φ) = GM·sin(φ)`.

That collapses to one memorable, exact design rule:

> **Keep the combined center of gravity below the bottle's central axis.** (KG < R.)

Belly ballast (40 g in the lowest pocket) does exactly this. At the reference build KG ≈ 34 mm < 45 mm,
GM ≈ +11 mm, and GZ is positive through 90° — the hull returns antenna-up from any roll. Move the
ballast up toward the axis (e.g. `--ballast-z 85`) and the tool correctly reports **FAIL** (GM < 0).

## What this proves — and what it does not

- ✅ **Initial roll stability and the antenna-up preference** are computed positive with margin, and the
  design rule (CG below axis) is exact for this geometry. A gross error (ballast in the wrong place,
  top-heavy payload) is caught here, cheaply, before cutting foam.
- ❌ It does **not** prove the full behaviour. Small-angle metacentric theory and a uniform prismatic
  section ignore the neck/cap taper, the ends, free-surface effects if partially flooded, wave dynamics,
  and dynamic overshoot. The **single stable equilibrium = antenna-up**, the recovery time, and behaviour
  in chop are confirmed only by the **tank/pool test** (VERIFIED_BUILD_TEST **T4**, re-run as **T7** with
  the solar payload installed). Masses here are **estimates — measure your build and edit them.**

Per the project ethic: no improvement claim before measurement. This calculation sizes and de-risks the
design; the water has the last word.

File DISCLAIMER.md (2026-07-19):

# Disclaimer

SEA:CUT / Friendly Floaty is an open-source design published in good faith. **We do not ship certified
finished units.** You build it, you own your deployment, and you follow your local rules.

- **You are responsible for your deployment.** Radio / telecom conformity assessment, water-body permits,
  wildlife and other water users, and battery / e-waste handling are the deployer's responsibility. See
  [docs/DEPLOY_responsibly.md](docs/DEPLOY_responsibly.md) and DIY_DIVERSITY §4.4 (localization hard-gates:
  radio type-approval, SIM/roaming legality, water sign-off, drone rules).
- **Recover what you release** (count-in = count-out). A unit left in the water is the exact problem we
  fight. If you cannot recover it, do not release it.
- **No warranty.** The designs, firmware, docs, and data are provided **"as is", without warranty of any
  kind**, to the extent permitted by law. The authors and contributors are **not liable** for any loss,
  damage, injury, or regulatory consequence arising from building or deploying a unit.
- **Wildlife & other users.** Smooth, non-entangling shapes; low-profile / break-away recovery loops;
  avoid protected areas and breeding seasons unless locally cleared; notify nearby fishers / harbor
  authority so an unknown sealed electronic box does not become an alarm.
- **Honest limits.** Cellular (not satellite) — coverage is river / estuary / near-coast; open sea is out
  of scope. Positioning and track assembly are physics, **not learned-AI prediction**. All buoyancy,
  power, and drift figures are **estimates** until bench + field measurement. Data is **effort / path
  signal**, not pollution flux or total.

By building or deploying a unit you accept these terms and your local legal responsibility.

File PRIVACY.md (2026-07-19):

# Privacy

The drifter observes **device positions on the water, not people.** Still, a few rules keep every
deployment privacy-preserving.

- **No personal data in the payload.** The ping schema ([data/schema.md](data/schema.md)) carries only
  `device_id`, position, time, battery, and QC fields — no personal fields. For **Tier 0
  (phone-in-a-bottle)**, never let the phone's SIM / IMEI / phone number reach the ingest server.
- **Release-point blurring.** Public snapshots blur exact release coordinates (k-anonymity) where a
  precise release point could identify a specific person or private property.
- **QR / contact labels.** The recovery QR points to an **organization** contact, not a personal phone.
  Handle any finder's contact details under local data-protection law (Korea PIPA / EU GDPR) and do not
  put them in the open data commons.
- **Retention.** Any cohort dataset has a stated retention window. If a deployment uses a recruitment or
  voice-application flow, that PII lives in a **separate private store** with a purge schedule — never in
  the CC BY data commons.

Data is CC BY (open); personal data is simply **not data we collect**. If in doubt, do not collect it.

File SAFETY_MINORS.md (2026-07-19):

# Safety — Minors & School Deployments

**River water + lithium cells + minors** is the highest-risk combination this project touches. These
rules are **mandatory** for any deployment involving under-18 participants and sit on top of the field
SOP ([hardware/PRELAUNCH_RECOVERY_CHECKLIST.md](hardware/PRELAUNCH_RECOVERY_CHECKLIST.md)) and the cell
safety rules (kernel K3 / [hardware/RELIABILITY.md](hardware/RELIABILITY.md)).

## Non-negotiable
- **No water entry by students.** Students release, observe, and record from inside a railing / deck
  only. **Recovery is done by adults.** The default is an **indoor tank / school pond** release; open
  water is an option *only* when the PRELAUNCH access-class gate passes (A/B; C = no release).
- **Lithium & soldering are adult-only.** Charging, sealing, and any soldering are handled by staff.
  Protected cell only; no charging below 0 °C or heating above 45 °C; contain a single-cell failure.
- **Supervision ratio** ≥ ~1 adult : 6 students near any waterside; a qualified safety officer
  (CPR / water-rescue) per class wherever open water is used; life jackets for the near-water group.
- **Consent & imaging.** Guardian consent for participation and for any images; **no student PII** in
  the data commons ([PRIVACY.md](PRIVACY.md)).
- **Insurance.** Event liability + participant accident insurance; the whole release/recovery is run
  under teacher supervision and documented.
- **Stop triggers.** Rain/flow/ice forecasts abort the waterside activity → switch to the remote /
  tank form. Recover 100% (count-in = count-out).

## School-record (세특) note — Korea
A student-record (세특) entry is possible **only when a teacher runs the program as regular class**
(subject / 창체 / 자유학기). External-instructor delivery and external awards are **not** record-eligible.
Deliver as **teacher-run** (with an optional short online pre-lesson), never as an outside contest.

The lowest-risk form is the **remote / non-waterside** variant: staff pre-release real FF-ID units and
students study the live trajectory in the classroom — no water access, no minors near lithium in water.

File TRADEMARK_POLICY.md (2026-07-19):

# Trademark & Badge Policy

The open licenses (CERN-OHL-S for hardware, MIT for firmware, CC BY-SA for docs, CC BY for data)
free the **designs, code, docs, and data**. The **names and badges** — "SEA:CUT", "Friendly Floaty",
and the "Friendly Floaty Compatible" badge — are governed separately, on the Precious Plastic model:
**the marks are conditional on safety and recovery, and may be revoked on violation.** A permissive
data license cannot police safety; this policy gives the safety rules teeth.

## You MAY, without asking
- Build, modify, manufacture, sell, and deploy units under the open licenses.
- Describe your build as "based on" / "derived from" SEA:CUT / Friendly Floaty (accurate attribution).
- Fork the docs and translate them (CC BY-SA / CC BY terms).

## You MAY use the "Friendly Floaty Compatible" badge only if
- Your variant self-declares **all four kernels** — K1 poolable schema · K2 recover-first ·
  K3 verified float · K4 honest labels — **and attaches per-unit hash evidence** (DIY_DIVERSITY §4.2).
- You follow **recover-first** (count-in = count-out; access-class C = no release) and **cell safety**
  (protected Li-ion, low-temp charge cutoff, no toxics, cell-failure containment).
- You keep the **honest labels**: cellular ≠ satellite · physics/positioning ≠ learned AI · all
  buoyancy/power/drift figures are estimates · effort (litter picked) ≠ pollution total.

## The marks are revoked if
- A build is presented as "Friendly Floaty" / "SEA:CUT" while breaking recover-first, cell safety, or
  the honest labels; or emits data under the name **without passing the provenance gate** (§4.1);
- The "Compatible" badge is claimed without per-unit evidence (that is the `unverified` state, not
  Compatible).

Enforcement is social and mechanical, not surveillance: a non-compliant build is simply "not official
Friendly Floaty and not in the shared dataset." Mark disputes: 사단법인 이타서울 (Itaseoul) / GAA.

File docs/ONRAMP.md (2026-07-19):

# On-ramp — from zero to your first drifter

> The shortest honest path into SEA:CUT. Pick where you start, follow the numbered steps, keep the
> four rules. Every step links to the canonical doc — this page only puts them in order.
> Kernel/shell rationale and the full tier table: [DIY_DIVERSITY.md](DIY_DIVERSITY.md). 한국어 요약은 맨 아래.

## 1. Pick your on-ramp (30 seconds)

Lower tiers are always open — start where your budget and skills are, move up later.

| You are | Start at | Cost (USD) | Solder? | First goal |
|---|---|---|---|---|
| School / citizen / low-resource | **Tier 0** phone-in-a-bottle | 5–35 | none | prove the pipeline with 0 lines of code |
| Maker beginner | **Tier 1** cellular bottle (default) | 40–80 | none (JST/uFL/USB) | the default upcycled float |
| Estuary / long-dwell | **Tier 1.5** solar-assisted | 65–100 | a little | extend reporting life |
| City / repeated campaigns | **Tier 2** robust | 90–180 | none–little | durable reusable unit |
| Research / long autonomous | **Tier 3** | 180+ | yes | long deployment |

Full tier table and parts: [../README.md](../README.md) · [../hardware/BOM.md](../hardware/BOM.md).

## 2. The pipeline you are building

```
[drifter] --GPS fix--> --cellular (LTE) POST--> [ingest] --> [public map / open data]
```

One coordinate per wake; a server assembles the track. Cellular (LTE), so coverage is river,
estuary, and near-coast — **not** open sea (that needs satellite backhaul, out of scope here).

## 3. Build order (Tier 1, the default)

1. **Parts** — order from [../hardware/BOM.md](../hardware/BOM.md). Reference board is the LILYGO T-A7670G R2; pick the A7670 band variant for your region.
2. **A float that survives first** — meet buoyancy F1/F2 and non-toxic power *before* anything else: [../hardware/FLOAT_STANDARD.md](../hardware/FLOAT_STANDARD.md).
3. **Three printed inserts** — electronics bracket, ballast keel, recovery loop. Measure your bottle, edit one `.scad`: [../hardware/cad/README.md](../hardware/cad/README.md).
4. **Firmware** — flash ESP32 + A7670 + L76K, one ping per wake: [../firmware/](../firmware/).
5. **Payload** — POST the minimal JSON per schema (FF-ID v1.1): [../data/schema.md](../data/schema.md).
6. **Before you release** — clear the recovery gate (plan, owner, deadline, cross-check evidence): [../hardware/PRELAUNCH_RECOVERY_CHECKLIST.md](../hardware/PRELAUNCH_RECOVERY_CHECKLIST.md).
7. **Deploy responsibly** — your local rules, protected areas/seasons, tell nearby water users: [DEPLOY_responsibly.md](DEPLOY_responsibly.md).

**Fastest possible test:** Tier 0 skips steps 3–4 entirely (a reused phone + GPSLogger, tethered,
Class-A only) — the quickest way to exercise the whole pipeline with zero code.

**Staying out for weeks?** Add solar without a new printed part: [../hardware/TIER1_5_SOLAR_DRIFTER.md](../hardware/TIER1_5_SOLAR_DRIFTER.md);
power detail in [../hardware/ELECTRONICS_POWER.md](../hardware/ELECTRONICS_POWER.md). ★Solar extends power, not coverage.

## 4. The four rules (non-negotiable — they travel with the design)

1. **Recover what you release.** A device left in the water is the very problem we fight.
2. **Safe power, no toxics.** Protected Li-ion, no primary lithium, contain a cell failure, non-metallic housing.
3. **Do no harm to the water or its users.** Smooth non-entangling shapes; avoid protected areas and seasons.
4. **Own your deployment, follow local rules.** Wireless type-approval, SIM legality, water sign-off, and drone rules are hard gates.

One-line kernel test: if a change (1) breaks data pooling, (2) makes recovery hard or impossible,
(3) stops it floating / self-righting or submerges the antenna or endangers the cell, or (4) inflates
the claim — you touched the **kernel**, not the shell. Everything else is yours to adapt.

## 5. From blueprint to a validated project

This repo is a reference design; every buoyancy, power, and drift number is an **estimate until bench
and field measurement**. The shortest honest path — bench gates, one small release, a citable DOI
deposit — is [VALIDATION_CAMPAIGN.md](VALIDATION_CAMPAIGN.md).

## 6. Contribute

Build a unit, release and recover it in your river, POST trajectories, add your river and your locale
notes. Fork, improve, translate, open a pull request.

---

## 한국어 요약

처음 오는 사람을 위한 진입 순서입니다. **아래 티어로 내려갈 자유는 늘 열려 있으니**, 예산·기술에 맞는 곳에서
시작해 나중에 올라가면 됩니다.

- **Tier 0**(폰인병, 5~35달러, 코드 0줄) = 파이프라인을 가장 빨리 시험 · **Tier 1**(기본 업사이클 병, 40~80달러, 무납땜) = 표준 빌드.
- 빌드 순서: 부품([../hardware/BOM.md](../hardware/BOM.md)) → **부력 F1/F2·안전 전원 먼저 통과**([../hardware/FLOAT_STANDARD.md](../hardware/FLOAT_STANDARD.md)) → 3부품 프린트([../hardware/cad/README.md](../hardware/cad/README.md)) → 펌웨어([../firmware/](../firmware/)) → 스키마대로 POST([../data/schema.md](../data/schema.md)) → 방류 전 회수 게이트([../hardware/PRELAUNCH_RECOVERY_CHECKLIST.md](../hardware/PRELAUNCH_RECOVERY_CHECKLIST.md)) → 책임 배포([DEPLOY_responsibly.md](DEPLOY_responsibly.md)).
- 장기 잔류는 솔라 보조([../hardware/TIER1_5_SOLAR_DRIFTER.md](../hardware/TIER1_5_SOLAR_DRIFTER.md), 솔라=전력↑이지 커버리지 아님).
- **네 규칙**(회수·안전전원·무해·현지규정 준수)은 설계와 함께 이동하는 커널입니다. 판별 한 줄과 티어 상세는 [DIY_DIVERSITY.md](DIY_DIVERSITY.md).
- 설계도 → 검증된 프로젝트 경로: [VALIDATION_CAMPAIGN.md](VALIDATION_CAMPAIGN.md).

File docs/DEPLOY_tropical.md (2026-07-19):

# Locale profile — tropical / monsoon (worked example: Da Nang, Vietnam)

A second locale profile, the way [OPEN_HARDWARE_BOM_global.md](OPEN_HARDWARE_BOM_global.md) §5 invites: keep the
universal rules, swap the locale-specific lines. This one collects what changes when you move the reference
design from a Korean temperate river to a **warm, monsoon-driven, high-UV** coast.

> **Honesty first.** The reference design has **not been validated anywhere yet** (see
> [VALIDATION_CAMPAIGN.md](VALIDATION_CAMPAIGN.md)), let alone in the tropics. Everything here is **planning
> guidance, not tested results** — treat each item as a hypothesis to confirm on your own bench and first
> release. The four rules (recover-first, safe power, do-no-harm, own-your-deployment) are unchanged.

## What changes in warm water

- **Heat, not cold, is the battery limit.** The temperate build worries about charging below 0 °C; here the
  risk is the opposite — a sealed dark enclosure in tropical sun can pass the **45 °C** upper charge/float
  limit and cook the cell. Keep the housing light-coloured or shaded, watch the JEITA upper taper, and for the
  solar variant the NTC cutoff ([../hardware/cad/params.scad](../hardware/cad/params.scad) `solar_ntc`) does the
  high-temp stop. Li-ion calendar aging also accelerates with temperature — do not leave charged units baking
  between deployments.
- **Biofouling is faster.** Warm, productive water fouls a hull in days, not weeks; fouling adds drag and mass
  and shifts the drift signal. Plan **shorter dwell before recovery**, inspect for growth, and note fouling in
  the unit `fate`/notes. This makes recover-first even more central.
- **UV ages the bottle faster.** Tropical UV embrittles PET quicker. For anything beyond a short release,
  prefer a UV-stable housing (Tier 2) or expect the PET to be single-use — and never let an embrittled unit
  become the litter you fight.
- **The flood regime dominates even more.** River litter transport is already flood-driven (schema §4.5); a
  monsoon coast concentrates that into the wet season. A fair-weather drifter under-samples the very events
  that matter — so scope claims tightly and time releases against the monsoon, not against the calendar.
- **Monsoon reversal is real and measurable.** Off Da Nang the surface drift reverses seasonally (roughly
  south-ish in winter, north-ish in summer). That is a genuine physical signal a drifter can help *observe* —
  but it is **not** a "trash flows from A to B" story on its own; keep windage/Stokes covariates separate
  (schema §4.5) and never fabricate a single cross-basin trajectory.

## Locale-specific lines to swap

- **Radio / SIM.** Use the **A7670G** global band variant. Vietnamese carriers (Viettel / Vinaphone /
  MobiFone) — confirm the LTE bands your carrier uses, or use a global IoT roaming SIM and confirm which local
  network it attaches to. A hand-built transmitter is regulated in Vietnam as elsewhere; check the local
  type-approval / research-exemption path before a multi-unit release.
- **Water authority.** Identify who manages your reach (river basin authority, provincial DONRE, coastal/port
  authority) and get sign-off; start on an ordinary tributary, not a protected or heritage stretch.
- **★ Data-residency (Vietnam).** Vietnam's data law can require personal/location data on Vietnamese
  citizens to be **stored in-country**. Coordinates of a drifter are not personal data, but any deployment
  that links coordinates to people (participants, addresses) must keep that linkage in-country. Follow the GAA
  Vietnam practice: **store coordinate/participant data on Vietnamese infrastructure**, and keep the open FF-ID
  export (CC BY) to non-personal trajectory fields only. Confirm current law before collecting.

## Bench additions before a tropical release

On top of the standard Stage-0 gates ([VALIDATION_CAMPAIGN.md](VALIDATION_CAMPAIGN.md)):

- [ ] **Hot-soak the charge cutoff:** confirm the unit stops charging as the enclosure approaches 45 °C (heat it, watch the NTC/JEITA behaviour). Do not skip this — it is the tropical-specific safety gate.
- [ ] **Short-dwell fouling check:** leave a unit in local water for the planned dwell and inspect drag/mass change before trusting a longer release.
- [ ] **UV / housing:** decide single-use PET vs UV-stable housing for your dwell, honestly.
- [ ] **Recovery is harder in monsoon flow:** rehearse recovery at the flow you actually expect, not calm water.

Add your measured tropical notes back here (and to [DIY_DIVERSITY.md](DIY_DIVERSITY.md)) so the next builder in a warm-water basin starts from data, not from this hypothesis.

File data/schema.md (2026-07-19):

# Data schema (CC BY 4.0) — Friendly Floaty standard (FF-ID)

시민이 만든 하천쓰레기 표류 관측의 표준·인용 가능 포맷. 데이터는 열려 있고(CC BY), 허브의 힘은 데이터를 가두는 데 있지 않고 **인용 표준·프로버넌스·실시간 지도·커뮤니티**에 있다. 누구나 내려받아 쓰되 인용한다.

**Schema version: 1.1** — v1.0 → 1.1 변경: 디바이스 fix 시각(`ts_fix`)·레코드 시퀀스(`seq`)·샘플링 간격(`sample_interval_s`)·측위 품질(`fix_quality`)·GNSS 출처·좌초 상태(`motion_state`)·**유닛 메타데이터 디렉토리**·**QC/store-and-forward 규칙**을 추가. 근거는 NOAA GDP 메타데이터 관행과 선행사례 연구(`docs/사례연구_기구제작_운영_데이터.md`).

> **정직 가드**: `medium=freshwater`·`link=cellular`(위성 아님)는 설계 고정값. 위치·상태는 물리 계산이지 학습 AI 예측 아님. 조립 트랙·모든 표류 수치는 추정(`is_estimate`).

---

## 1. Ping (디바이스 → 서버) — 최소 페이로드

디바이스는 웨이크마다 최소 페이로드만 보낸다. 서버가 인용 id·프로버넌스를 부여하고 트랙을 조립하며 QC를 돌린다.

`POST /api/observations/drift/ping` (번들 `ingest_server.py`는 `POST /api/ping`)

```json
{"device_id":"river-001","site_id":"nakdong-hakjang","seq":1487,"lat":35.10560,"lon":128.94310,"batt":4.02,"ts_fix":"2026-07-10T09:00:00Z","sample_interval_s":900,"fix_quality":1.4,"gnss_source":"l76k"}
```

| field | type | required | note |
|---|---|---|---|
| device_id | string | yes | 디바이스 식별자(공개 스냅샷에선 익명화) |
| site_id | string | no | 사이트 태그 (예: `nakdong-hakjang`) |
| **seq** | integer | **yes** | **디바이스별 단조증가 레코드 카운터.** store-and-forward 핵심 — 버퍼링돼 늦게 온 핑도 도착순이 아니라 seq로 정렬·중복제거 |
| lat | number | **yes** | **EPSG:4326(WGS84), 소수 ≥5자리(≈1m).** 저정밀 절단은 거부/플래그 |
| lon | number | **yes** | 동일 |
| batt | number | no | **볼트** 단위 |
| **ts_fix** | string | **yes\*** | **디바이스 GPS fix 시각, ISO8601 UTC.** 실제 관측 시각(서버 수신시각과 구분) |
| **sample_interval_s** | integer | **yes** | **공칭 핑 간격(초).** 혼합 주기 데이터를 가중·층화하려면 필수. "펌웨어 자유의 조건 = 핑 간격 신고" |
| **fix_quality** | number | no | HDOP(없으면 sat_count). 없으면 down-weight |
| **gnss_source** | string | no | `l76k` / `phone` / `other` |
| motion_state | string | no | 디바이스 힌트 `afloat`/`stranded`/`unknown`(서버도 추론) |

\* `ts_fix` 결측 핑은 거부하지 않고 §2 `ts_source=server_recv`로 **강등 수용**한다(`is_estimate` 상향; 버퍼 지연 전송 시 관측시각 신뢰 불가). 단 디바이스는 반드시 채워 보내는 것이 표준이다.

---

## 2. Observation record (서버 부여, 인용 가능)

서버가 수용된 핑마다 인용 레코드로 감싼다. 공개 스냅샷·다운로드가 노출하는 형태.

```json
{
  "obs_id": "FF-KR-BS-20260710-001524",
  "schema_version": "1.1",
  "ts_fix": "2026-07-10T09:00:00Z",
  "server_recv_ts": "2026-07-10T09:03:11Z",
  "ts_source": "device_fix",
  "seq": 1487,
  "device_id": "d1yo2o4q",
  "site_id": "nakdong-hakjang",
  "lat": 35.10560, "lon": 128.94310, "crs": "EPSG:4326",
  "batt": 4.02,
  "sample_interval_s": 900,
  "fix_quality": 1.4, "gnss_source": "l76k",
  "position_uncertainty_m": 3.5,
  "motion_state": "afloat",
  "env": { "wind_source": "era5", "wind_u_ms": -2.1, "wind_v_ms": 0.8, "hs_m": null, "stokes": "not measured — join from reanalysis; keep separate from windage" },
  "qc": { "velocity_4sigma": "pass", "is_estimate": false, "censoring": "none" },
  "provenance": { "source": "device", "verification": "raw", "operator": "gaa-kr-busan" },
  "calibration_ref": "ff-drifter-v1",
  "medium": "freshwater", "link": "cellular",
  "license": "CC BY 4.0"
}
```

| field | 의미 |
|---|---|
| obs_id | 전역 유일·인용 id. 형식 `FF-<country>-<region>-<YYYYMMDD>-<seq>`. **서버가 부여**(자체생성 금지). 이걸 인용 |
| ts_fix / server_recv_ts | 디바이스 fix 시각 / 서버 수신 시각. **분리 저장** |
| ts_source | `device_fix`(ts_fix 있음) / `server_recv`(없어 수신시각 대체 → `is_estimate` 상향). ★큰 지연은 Tier0 배치덤프의 "순간이동 가짜궤적" 신호 |
| **position_uncertainty_m** | 위치 불확실성(m). HDOP×UERE 또는 L76K CEP(~2.5m). ★저장정밀도(≈1m) ≠ GNSS 실측 정확도 |
| **env** | co-located 바람(실측/재분석 ERA5·GFS·KMA)·유의파고. **Stokes(파랑유도)는 windage와 분리**·미측정 시 명시(§4.5) |
| **qc.censoring** | 검열·선택 편향 플래그: `none`/`right_censored`(외해 이탈)/`nearshore`/`fair_weather`(§4.5) |
| qc.velocity_4sigma | 2단계 4σ 속도 QC 결과(§4) |
| motion_state | `afloat`/`stranded`/`unknown` — stranded는 표류 통계서 제외/태깅 |
| provenance.verification | `raw` / `auto_checked` / `steward_verified`(실제 스튜어드·기관 확인 시에만, 날조 금지) |
| medium/link | 고정값 `freshwater`/`cellular`(위성 아님) |

---

## 3. Unit metadata directory (유닛별, GDP식) — 신설

NOAA Global Drifter Program 관행 채택: 각 물리 유닛은 **방류·종료·운명(fate)·하드웨어** 디렉토리 레코드를 갖는다. 그래야 트랙 통계가 "조용한 유실"로 편향되지 않는다(회수-우선 정산과 연동).

```json
{
  "unit_id": "FF-KR-BS-U0042",
  "hardware": { "tier": "T1", "board": "lilygo-t-a7670g-r2", "housing": "pet-1L",
                "calibration_ref": "ff-drifter-v1", "verified_build": true },
  "deploy": { "ts": "2026-07-10T09:00:00Z", "lat": 35.132, "lon": 128.968,
              "session_id": "busan-hakjang-2026-07-10", "access_class": "B" },
  "end":    { "ts": "2026-07-10T16:30:00Z", "lat": 35.071, "lon": 128.947,
              "fate": "recovered", "recovery_evidence": { "last_gps": true, "heartbeat_ceased": true } },
  "epoch": "seconds since 1970-01-01T00:00:00Z"
}
```

- **fate 어휘**(회수 체크리스트와 통일): `recovered` · `stranded` · `sunk` · `signal_lost` · `drifted_out` · `retrieved_damaged`.
- **fate 결정규칙**(모호성 제거): `sunk`=마지막 fix 수면하 유속·급강하 후 신호 소멸 + 회수 시 침수 확인 / `signal_lost`=커버리지 내인데 heartbeat 소거(물리 유무 불명·재부팅 대기) / `drifted_out`=마지막 fix가 회수구간 밖 + 커버리지 경계 방향 / `stranded`=지속 근제로 변위. 판정 근거 = 마지막 유효 fix·마지막 heartbeat·회수 물증.
- ★`fate=recovered`는 **증거 필수**(마지막 GPS 종점 + heartbeat 소거). 증거 없으면 `unverified_recovery`로 표기(정산 위조 차단).
- `verified_build=true`는 [FLOAT_STANDARD.md](../hardware/FLOAT_STANDARD.md) F1·F2 통과 유닛만.

---

## 4. 품질관리(QC) — 신설/확장

- **2단계 4σ 속도 QC**(NOAA GDP, Hansen & Poulain 방식): 연속 fix 간 속도를 **전진·후진 유한차분** 양쪽으로 계산해, **둘 다** 국지 속도분포의 4σ를 넘으면 그 점을 bad로 플래그. GPS·셀룰러 이상치 점프에 강건.
- **좌초 탐지**: 지속적 근제로 변위 → `motion_state=stranded`. stranded 점군은 태깅·표류/이송 통계서 제외(둔치 좌초 유닛의 정적 점군이 분산·이동 통계를 오염시키지 않게).
- **store-and-forward 정렬**: 서버는 `ts_fix`로 정렬하고 `seq`로 중복제거·결측 탐지. **도착 순서를 신뢰하지 않음**(Duncan·Merlino·Kang 공통 검증).
- 원시 fix 저장 우선(GPS ≈ 10m 규칙 측위이므로 무거운 크리깅 생략, gap/error 플래그만 공개).

---

## 4.5 알려진 편향·물리 공변량 (관측과학 정직 경계 — 필수)

저건현 부유체는 **완전 라그랑주 추종자가 아니다**(van den Bremer & Breivik 2021: 부유 쓰레기는 해류에 windage·Stokes가 겹침). 이를 문서화하지 않으면 데이터는 물리적으로 해석 불가하다.

- **바람·파랑 공변량(`env`)**: 개별 fix에 windage를 적용하려면 co-located 바람이 필요 → 방류 중 실측 바람(가능 시 유의파고·주기) 또는 재분석(ERA5/GFS/KMA)을 **시각·좌표로 조인**한다. **Stokes(파랑유도) 표류는 windage와 분리**해 다루며, 미측정 시 `env.stokes="not measured"`로 명시한다.
- **위치 불확실성(`position_uncertainty_m`)**: HDOP×UERE 또는 L76K CEP(~2.5m)에서 유도하고, 속도 산출 시 불확실성을 전파한다. **좌표 저장정밀도(≥5자리≈1m)와 GNSS 실측 정확도(~2.5m CEP)는 다르다** — 혼동 금지.
- **검열·선택 편향(`qc.censoring`, 반드시 명명)**: (a) 셀룰러 이탈 = 외해 도달 유닛의 **우측 검열**(`right_censored`, 신호 끊긴 뒤 궤적 미관측) (b) 회수-우선 = **근안 편중**(`nearshore`) (c) 정화이벤트 기반 = **평수·호천후 과대표집**(`fair_weather`). 하천 쓰레기 수송은 실제로 **홍수 지배**(상위 5% 유량, Do et al. 2026)인데 평수 드리프터는 그 레짐을 표집하지 못한다. → 데이터 **주장 범위를 "하천 내·근안·평수 표층 표류"로 한정**하고 flux·오염총량으로 확대하지 않는다.
- **QC 적용 범위 주의**: 4σ 속도QC(Hansen & Poulain 1996)는 외해 평활·보간 데이터 기준이라, 원시·불규칙 하천 fix에 적용하면 **홍수 펄스·좌초를 이상치로 오탐**할 수 있다 → 하천에선 물리 상한(구간 유속)과 병용한다.

---

## 5. Calibration commons

전이 가능한 과학 자산. 각 드리프터 형상은 하천이 아니라 물체의 성질인 windage/drag 계수를 가져 하천 간 이동한다.

```json
{"calibration_id":"ff-drifter-v1","form":{"attitude":"horizontal (belly-ballasted, self-rights antenna-up)","freeboard_ratio":0.2,"submerged_ratio":0.8},"windage_alpha":0.012,"windage_alpha_sd":null,"validated_sites":[{"site":"nakdong-hakjang","windage_alpha":0.013,"alpha_sd":0.003}],"notes":"alpha=BORROWED seed (Kang 2025), NOT self-calibrated. drag_area_ratio omitted: a dragless bottle is not an SVP holey-sock drogue (~40); form-derived drag pending bench+field."}
```

- windage 초기값은 **Kang 2025 제주 하구 실증(α 0.012~0.014, 저건현 PET는 해류 지배)** 을 근거로 낮게 잡고, 정점별 α를 실증 보정해 커먼즈에 되돌린다. 새 사이트는 이 프로파일을 재사용해 적은 드리프터로 보정한다.
- ★**정직 경계**: 이 α는 **차용 시드**일 뿐 **자체 보정 전**이라 `windage_alpha_sd=null`이다 — "이전 가능 커먼즈"로 과대라벨 금지. `form.attitude`는 **단일값 고정**(수평·벨리밸러스트 자기복원)이며, 드로그 없는 병에 SVP식 `drag_area_ratio`(~25.6, 드로그형 ~40에 근접)를 쓰지 않는다(형상유도 drag는 벤치+현장 후 도입). 형상(자세·건현·침수비)이 다른 물체는 **반드시 새 calibration_id로 fork**(geometry_hash 바인딩, DIY_DIVERSITY §5.1). 레지스트리 변형에 `form` 필드로 등록해 다른 물리의 물체가 같은 프로파일로 섞이지 않게 한다.

---

## 6. Self-host / share

자체 서버(`ingest_server.py`)를 돌리거나 공유 커뮤니티 지도에 POST한다. 둘 다 같은 스키마라 데이터가 상호운용된다. **스키마 미준수 = 공유 데이터셋 미포함**(강제 아님, 게이트).

국제표준 상호운용: FF-ID를 **CF-NetCDF(DSG trajectory)·OGC SensorThings·EMODnet Physics**에 매핑한 crosswalk와 무의존성 exporter가 있다 — [../docs/DATA_STANDARDS_CROSSWALK.md](../docs/DATA_STANDARDS_CROSSWALK.md), [export_standards.py](export_standards.py). ★드리프터 트랙은 **trajectory이지 GBIF/Darwin Core occurrence가 아니다**(생물다양성 레지스트리에 넣지 않는다).

## 7. Citation

`obs_id`로 인용한다. 예:

> Friendly Floaty (SEA:CUT) Open Data (2026), observation FF-KR-BS-20260710-001524, CC BY 4.0.

## 8. Changelog · 하위호환

- **1.0 → 1.1**: `ts`(모호) → `ts_fix`+`server_recv_ts`로 분리(1.0 `ts`는 `ts_fix`로 매핑). 신규 필수 `seq`·`sample_interval_s`; 신규 선택 `fix_quality`·`gnss_source`·`motion_state`·`qc`·`crs`. 유닛 메타데이터 디렉토리(§3)·QC(§4) 신설.
- 혼합 버전 집계 규칙: `schema_version` 별로 필드 매핑 후 합친다. 1.0 레코드는 `ts_source=device_fix` 가정하되 `sample_interval_s` 없으면 `raw`로 강등(가중 불가).

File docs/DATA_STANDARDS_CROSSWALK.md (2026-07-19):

# FF-ID ↔ international standards crosswalk

FF-ID (the Friendly Floaty observation format, [../data/schema.md](../data/schema.md)) is a **native, lightweight citizen-science format**. It is deliberately small so a hand-built device and a one-file server can speak it. But small does not mean isolated: a drifter trajectory is an ordinary geophysical object, and the recognized standards for "a thing that moves through water reporting time + position" already exist. This page maps FF-ID onto them so the data lands in the right registries and combines with professional datasets instead of sitting in a private silo.

**The one boundary that matters first.** A Friendly Floaty record is a **Lagrangian trajectory of a tracked object** — where it went, when. It is **not a biodiversity occurrence**. It therefore belongs in:

- **CF conventions** — Discrete Sampling Geometry, `featureType = "trajectory"` (the canonical NetCDF encoding for a moving platform)
- **OGC SensorThings API (STA)** — the OGC standard for IoT sensor observations
- **EMODnet Physics** — the European marine in-situ hub that already ingests drifter/float trajectories (via SeaDataNet/BODC vocabularies and CF-NetCDF)

…and it does **not** belong in **GBIF / Darwin Core / OBIS** (species-occurrence registries). Submitting a drifter track as an "occurrence" is a category error and pollutes those datasets. If a record ever carries *what object was tracked* (a PET bottle, a derelict net), that litter-type attribute uses marine-litter vocabularies (UNEP/GESAMP, OSPAR, the EMODnet Chemistry marine-litter categories) — never a taxonomic rank.

---

## 1. Field crosswalk

FF-ID field → CF standard_name (NetCDF) · OGC SensorThings element · EMODnet/SeaDataNet note. Blank means "no standard equivalent — FF-ID-native housekeeping, carried as an ancillary/parameter."

| FF-ID field | CF (NetCDF DSG trajectory) | OGC SensorThings (STA) | EMODnet Physics / SeaDataNet |
|---|---|---|---|
| `unit_id` | variable with `cf_role = "trajectory_id"` | **Thing** (`@iot.id` / `name`) | platform id; EDMO for the operator org |
| `obs_id` | (row identity within the trajectory) | **Observation** `@iot.id` | citation id (keep as-is; it is the DOI-able unit) |
| `lat` | `latitude`, units `degrees_north` | Observation `FeatureOfInterest` (GeoJSON Point) | P01 `ALATZZ01`, P06 `DEGN` |
| `lon` | `longitude`, units `degrees_east` | Observation `FeatureOfInterest` (GeoJSON Point) | P01 `ALONZZ01`, P06 `DEGE` |
| `ts_fix` | `time`, units `seconds since 1970-01-01T00:00:00Z` | Observation `phenomenonTime` | observation time (UTC) |
| `server_recv_ts` | ancillary time variable | Observation `resultTime` | ingestion time (distinct from phenomenonTime) |
| `crs` (`EPSG:4326`) | `grid_mapping` → `latitude_longitude` (WGS84) | CRS of the GeoJSON (CRS84) | WGS84 |
| `position_uncertainty_m` | ancillary variable, `standard_name = ...status_flag`-adjacent; carry as `*_uncertainty` | Observation `parameters.position_uncertainty_m` | quality/uncertainty parameter |
| `batt` | non-CF housekeeping variable (`long_name = "battery voltage"`, units `V`) | its own **Datastream** (ObservedProperty = battery voltage, Sensor = board ADC) | housekeeping parameter |
| `env.wind_u_ms` | `eastward_wind`, units `m s-1` | Observation `parameters.wind_u_ms` | joined covariate; keep source in `wind_source` |
| `env.wind_v_ms` | `northward_wind`, units `m s-1` | Observation `parameters.wind_v_ms` | joined covariate |
| `env.hs_m` | `sea_surface_wave_significant_height`, units `m` | Observation `parameters.hs_m` | wave covariate (may be null) |
| `sample_interval_s` | global/traj attribute (`sampling_interval`) | Datastream `parameters.sample_interval_s` | temporal resolution metadata |
| `fix_quality` (HDOP) | ancillary `hdop` variable | Observation `parameters.fix_quality` | quality parameter |
| `gnss_source` | traj attribute | Sensor (`metadata`: L76K / phone) | instrument metadata |
| `motion_state` | status flag variable (`flag_values`/`flag_meanings`) | Observation `parameters.motion_state` | quality/status flag |
| `qc.velocity_4sigma` | `status_flag` (`flag_meanings = "pass fail"`) | Observation `parameters.qc_velocity_4sigma` | QC flag (cf. SeaDataNet QC L20) |
| `qc.censoring` | status flag variable | Observation `parameters.qc_censoring` | selection-bias flag (FF-ID-specific) |
| `qc.is_estimate` | ancillary status flag | Observation `parameters.is_estimate` | derived-vs-measured flag |
| `provenance.verification` | traj/global attribute | Observation `parameters.verification` | provenance (`raw`/`auto_checked`/`steward_verified`) |
| `calibration_ref` | global attribute | Datastream `properties.calibration_ref` | method/calibration reference |
| `medium` (`freshwater`) | global attribute | Thing `properties.medium` | platform environment |
| `link` (`cellular`) | global attribute | Thing `properties.link` | telemetry class (not satellite) |
| `deploy` / `end` / `fate` | trajectory start/stop + `fate` attribute | Thing `Locations` / `HistoricalLocations`; fate in `properties` | deployment/recovery metadata (GDP-style) |

Notes:
- **CF trajectory identity.** The whole track is one `featureType = "trajectory"` feature; the per-fix rows share one `cf_role = "trajectory_id"` variable (`unit_id`). This is exactly how NOAA GDP and Argo-adjacent drifter data are encoded — it is why FF-ID keeps a unit directory (§3 of the schema) instead of only loose pings.
- **SensorThings shape.** One drifter = one `Thing`; each measured quantity (position, battery) = a `Datastream`; each ping = an `Observation` with `phenomenonTime = ts_fix` and `resultTime = server_recv_ts`. The split of those two times (a store-and-forward requirement in FF-ID) maps *natively* onto STA — most formats lose it.
- **EMODnet reality check.** EMODnet Physics ingests professional in-situ platforms; a citizen drifter is accepted on its data-quality and metadata completeness, not by right. The crosswalk is what makes a submission *possible*; a DOI-deposited dataset (Zenodo/SEANOE) with these fields is the realistic first step, with EMODnet as a later goal once provenance is `steward_verified`.

---

## 2. Honest scope (carried from the schema)

The crosswalk does not upgrade the science. Everything in [../data/schema.md](../data/schema.md) §4.5 still holds after export:

- The data is an **effort/path signal and a Lagrangian trajectory**, not a pollution flux, total, or concentration.
- Coverage is **river / estuary / near-coast, fair-weather, surface** — right-censored at the cellular edge, nearshore-biased by recover-first, and blind to the flood regime that actually dominates river litter transport.
- Windage/Stokes covariates are **joined, not measured by the drifter**; keep them separate from the trajectory itself.
- Positions are GNSS fixes (~2.5 m CEP), not sub-meter survey; `position_uncertainty_m` propagates into any derived velocity.

Exporting to CF/STA/EMODnet **must not** silently drop these flags. The `qc.*`, `provenance.*`, `is_estimate`, and `position_uncertainty_m` fields are first-class in every target format above precisely so the caveats travel with the numbers.

---

## 3. Exporter

[../data/export_standards.py](../data/export_standards.py) — a zero-hard-dependency reference exporter. It reads FF-ID observation records (JSON, one per line) and emits:

1. **OGC SensorThings Observations** (JSON) — pure standard library, always available.
2. **CF-1.11 trajectory CDL** (`.cdl` text) — feed to `ncgen -o out.nc in.cdl` to get a real CF-NetCDF file with no Python NetCDF dependency. If `netCDF4` *is* importable, the exporter writes the `.nc` directly as well.

```
python3 data/export_standards.py observations.jsonl --sta out.sta.json --cdl out.cdl
# then, if you have the netCDF tools:  ncgen -o out.nc out.cdl
```

The exporter is a **starting point, not a certification**: it produces standards-shaped output that a domain data manager can validate (CF-checker, an STA endpoint, EMODnet's ingestion checks) before any real submission.

---

## References (external — not repo links)

- CF Conventions, Discrete Sampling Geometries, `featureType = trajectory` and `cf_role`.
- OGC SensorThings API Part 1: Sensing (Thing / Datastream / Sensor / ObservedProperty / Observation / FeatureOfInterest).
- EMODnet Physics — in-situ platforms incl. drifters/floats; SeaDataNet / BODC NERC vocabularies (P01 parameters, P06 units, EDMO organizations).
- NOAA Global Drifter Program metadata practice (unit directory, deploy/end/fate).
- Marine-litter categories: UNEP/GESAMP, OSPAR, EMODnet Chemistry marine-litter — for *object type*, never taxonomy.

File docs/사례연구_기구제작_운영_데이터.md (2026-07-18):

# 표류 드리프터 선행사례 연구 — 기구제작·운영실험·데이터기록 3축 분석

> **한 줄 요약:** NOAA GDP(위성·수중 15m 드로그·40년 표준)부터 OpenMetBuoy(오픈하드웨어 위성 부이), Duncan·Merlino·Kang·한강하구(PET·셀룰러 하천 드리프터), PlasticPirates·Precious Plastic(시민과학 거버넌스)·홍콩 Marine Litter Detective(학생 110대·11학교)까지 8개 선행사례를 **기구체 제작 / 운영 실험 / 데이터 기록** 세 축으로 해부해, Friendly Floaty(셀룰러 LTE·PET병·미회수 손실 감수·OpenDrift 보정)의 설계·운영·FF-ID 스키마에 그대로 이식할 교훈만 추린다.

---

## 0. 방법과 정직 고지

- 본 문서의 모든 수치에는 신뢰도 태그를 붙인다.
  - **[출처확인]** — canonical 문헌에서 직접 확인, 그대로 인용 가능.
  - **[단일출처·주의]** — 인용 가능하나 단일 문헌 의존, "○○ 논문 기준·교차검증 없음" 병기.
  - **[출처불명·표시필수]** — 뒷받침 공개 URL 없음. 단정 인용 금지, "출처 미확인" 딱지 필수.
- **미확인 항목(원가·통신방식·기구체 재료 등)은 임의 수치로 메우지 않고 "자료 없음"으로 둔다.**
- **배터리 수명의 "연 단위" 값(예: Duncan 6xAA 약 9년, OMB 약 4.5개월)은 대기전류/샘플링 기준 이론적 외삽 추정치이며 실측 운용수명이 아니다.**
- **폐기 처리한 수치:** Merlino(Case 4) 초록의 "2,845 km / 94일"은 (a)같은 논문 본문 실측 최장(852.59 km)과 3.3배 불일치, (b)Duncan(Case 3) B2 해상 궤적 수치와 완전히 동일 → 단일 드리프터 최대 성능으로 **절대 인용 금지·폐기**. 이 우연한 동일값으로 두 사례를 교차인용하지 않는다.
- **OpenDrift 귀속 정정:** Kang 2025(Case 5)는 OpenDrift를 사용하지 않았다(자체 VSC + windage 계수 분석).

---

## 1. 사례별 카드

### Case 1 — NOAA Global Drifter Program (SVP 드리프터)
**한 줄:** 40년 글로벌 표준. 구형 부표를 수심 15m holey-sock 드로그에 매달아 항력비 약 40으로 "물을 따라가게" 설계, 수천 기 방류·엄격 QC·안정적 메타데이터 디렉토리를 갖춘 데이터 스키마의 참조 원형 — 단, 목적(수중 해류 측정)이 FF(수면 쓰레기 추적)와 정반대다.

- **제작:** 민간사(Clearwater·Pacific Gyre·Technocean·Metocean·Marlin-Yug)가 DBCP 규격에 맞춰 제작. 부표 지름 30.5~40cm 구형, 초기 유리섬유 0.3~0.4cm 두께→현재 대부분 ABS. 드로그 중심 15m, 7섹션×92cm. 하부 습식면 산화구리 방오도료, 자석 풀 활성화. [출처확인]
- **운영:** 선미에서 투하, 항해 중 가능(최대 25노트 화물선 방류 실적). 종이테이프·수용성 종이관이 녹아 드로그 침강까지 약 1시간. **회수하지 않음** — 사멸·좌초·시민 습득·송신중단까지 자유표류, 유닛별 death code 기록. [출처확인]
- **데이터:** 고전형 Argos(401.650MHz) 도플러 측위, 정확도 150~1000m. 센서 90초 간격 7~10샘플 평균. QC = Hansen&Poulain 2단계(전진·후진 유한차분 양쪽 모두 4σ 초과 시 bad). Argos를 6시간 격자 크리깅, 신형 시간별 GPS(약 10m)/Iridium NetCDF. 메타데이터 디렉토리 = 방류/종료 시각·위경도·드로그상실일·death type·부이형·제조사·WMO/PTT ID, 수정 율리우스일(1979-01-01=1일). CF 규약 contiguous ragged array NetCDF·ERDDAP·NCEI·AWS 배포. [출처확인]
- **핵심수치:**
  - 항력비 설계목표 약 40(측정 37.5~45.9), 다운윈드 슬립 0.7 → 약 8.6 cm/s(드로그 유무, 풍속 10m/s당) [출처확인]
  - Argos 실측 RMS 630m(동서)/270m(남북), 측위 6~9회/일→16~20회/일(다위성) [출처확인]
  - **방류 규모 2003–04: 658기/년(R/V 440 + 화물선 201 + 항공 17)** — Lumpkin&Pazos 단일 챕터 기준 [단일출처·주의]
  - **유닛 원가 5,475 USD(1993, 2003$)→1,750 USD(2004)** — 동일 단일 챕터 [단일출처·주의]
  - 수명 약 400일(제조사 추정), 송신기 반감기 291일(1998)→485일(2001) [단일출처·주의]
- **출처:** [Lumpkin & Pazos 기술챕터](https://www.aoml.noaa.gov/phod/docs/LumpkinPazos.pdf) · [GDP Data FAQ](https://www.aoml.noaa.gov/phod/gdp/data_faq.php) · [Hourly Drifter Data](https://www.aoml.noaa.gov/phod/gdp/hourly_data.php) · [Elipot et al. 2016](https://agupubs.onlinelibrary.wiley.com/doi/full/10.1002/2016JC011716)
- **자료 없음:** 밸러스트 질량, 미니형 하우징 두께, 배터리 용량, 신형 GPS/Iridium 샘플링 주기, 드로그상실 판정 수치 임계값.

---

### Case 2 — OpenMetBuoy-v2021 (OMB, Rabault et al. 2022)
**한 줄:** 위성(Iridium) 오픈소스 표류·파랑 부이. MIT 라이선스로 설계·펌웨어·후처리 코드 전면 공개, 통합 캐리어 보드 전략으로 조립 0.5시간 — FF의 벤치마크 원형이나 통신이 위성이라 전력·통신 설계가 FF의 셀룰러와 갈린다.

- **제작:** SparkFun Artemis Global Tracker(MCU+GNSS+Iridium 통합) 1보드에 납땜 2곳·Qwiic 플러그로 조립. 9dof = ST ISM330DHCX + LIS3MDL. 전원 SAFT LSH20 리튬 D셀 2개 병렬 + Pololu 3.3V 벅. 부력=스티로폼(덕트테이프 감아 마모방지), 바닥 킬=볼트 스크랩, 에폭시 밀봉. IP68 12×12×9cm. [출처확인]
- **운영:** 검증 배치 4건(스발바르 해빙 11개월+·도쿄대 수조·NABOS 중앙북극에서 상용 SOFAR Spotter 동시방류·카리브해) → 2022 스발바르 주변 **70개 궤적+** 다기관. 표류형 미회수. [출처확인]
- **데이터:** GNSS 30분·파랑 스펙트럼 2시간. 파랑 = 원시 약 800Hz→3σ 100Hz 평균→Kalman(NED)→10Hz 수직가속도→20분 Welch(21세그·75%중첩), 0.05~0.5Hz. Iridium 9603 양방향(원격 샘플링율 변경), 바이너리 버퍼·무손실 재전송, Python 디코더 동봉. 3σ QC. SOFAR Spotter와 매우 양호 일치. [출처확인]
- **핵심수치:**
  - **BOM 부품비 562 USD(2021-10)** [단일출처·주의]
  - **6개월 총소유비용 약 1,200 USD(약 53%가 Iridium 통신료)** [단일출처·주의]
  - MCU Ambiq Apollo3 Blue, 보드 약 $375 [단일출처·주의]
  - **평균 18.7 mW, D셀 2개로 기본 샘플링 시 약 4.5개월** — 대기·샘플링 기준 추정(실측 아님) [단일출처·주의]
  - 실내 노이즈 하한 약 0.1cm, 조립 0.5시간/대, 무게 0.3~0.5kg [출처확인]
  - ※ "노르웨이 대량주문 약 650 USD/대가 BOM 562 USD보다 비쌈"은 반직관 → **인용 자제**.
- **출처:** [Geosciences 12(3):110](https://www.mdpi.com/2076-3263/12/3/110) · [arXiv:2201.08384](https://arxiv.org/abs/2201.08384) · [GitHub OpenMetBuoy-v2021a](https://github.com/jerabaul29/OpenMetBuoy-v2021a)
- **자료 없음:** GNSS 정확 모델명, 국제 메타데이터 표준 준수 여부, GNSS 수평 정확도(m), 2022 방류 정확 대수.

---

### Case 3 — Duncan et al. 2020 "Message in a bottle" (PLOS ONE)
**한 줄:** PET병에 담은 오픈소스 GPS 트래커 25기(GSM 10 + Argos 위성 15)를 갠지스강·벵골만에 방류 — 강에서는 약 40%가 수십 km 내 좌초, FF의 직계 조상 격.

- **제작:** 500mL PET병 개조 + CNC ABS 인클로저. 방수 = 2.5mm O링(가공 홈) + 안테나 개구부 Araldite 에폭시. Arribada Horizon GPS PCB(+위성형 ARGOS ARTIC R2), Icoteq 외주. 펌웨어 GPLv3·하드웨어 CERN OHL 1.2. [출처확인]
- **운영:** Phase A GSM 10기 인도(2019-05~07), Phase B 위성 15기 방글라데시+해상 3기(2019~2020-10~12). **체계적 회수 없음**, 시민 SIM 재사용 사례. 사이클론·어업 손실. [출처확인]
- **데이터:** Phase A GPS 3시간(30초 취득)·GSM→AWS(외곽 수신 불량). Phase B 4시간+위성통과(고도≥40°)·Argos. GPS마다 시계재동기. QC = Excel→ArcMap 10.7(WGS84)→R 3.6.2 sf. [출처확인]
- **핵심수치:**
  - 총 25기, 무게 약 130g(안테나 수면 위 유지) [출처확인]
  - **좌초율 약 40%(평균 72.2km 이동 후)** [출처확인]
  - 하천 최장 609.9km/51일, 해상 평균 41.6일/1,211.7±846.2km [출처확인]
  - **최장 단일 궤적 2,845km/94일(B2, 해상)** — 논문 본문 확인값. Merlino 초록 동일값과 우연 일치 → 교차인용 금지 [출처확인·주의]
  - idle 38 µA → **6xAA 약 9년+ 대기** = 대기전류 기준 외삽(실운용 수명 아님) [단일출처·주의]
  - **유닛 원가: 논문 미공개** [자료 없음]
- **출처:** [PLOS ONE](https://journals.plos.org/plosone/article?id=10.1371/journal.pone.0242459) · [PMC7710111](https://pmc.ncbi.nlm.nih.gov/articles/PMC7710111/)
- **자료 없음:** 유닛 원가·전체 BOM, Horizon 리비전, 제작 대수, 조립 주체, AA 외 밸러스트.

---

### Case 4 — Merlino et al. 2023 "Marine Litter Tracking System" (Arno강, 고교생 제작, Sensors 23(2):935)
**한 줄:** GSM/GPS 저가 드리프터를 고교생이 제작(목판형·절단 페트병형), Arno 하구에서 14기·5회 방류, 시간별 GSM 측위 + SD 폴백 + QR 기반 시민 회수.

- **제작:** 목판형 약 38×38×4cm 방수도장 나무, 병형 2~5L 절단 플라스틱 수지 재밀봉, 상단 전자박스 약 10×10×7cm 실리콘 밀봉. **밸러스트로 몸체 약 50% 수면 아래**. 상용 Winnes TPK-905(5000mAh) 또는 자작 MADUINO SIM808. 태양광 약 5×5인치. 제작=Capellini-Sauro 고교생. [출처확인]
- **운영:** Arno 하구(43.68202N/10.26484E ±0.005°) 5회: 2021-04-16·08-09·08-12·09-15·12-16. 방류시각 11:00 CET. **회수 실시**(QR "발견하면 연락"), 시민·국립공원·경찰 잠수팀 회수·재사용. 여름 방류 수시간 좌초. [출처확인]
- **데이터:** GPS+GSM(해안 약 10~20km), 상실 시 SD 로깅 후 지연 전송. 샘플링 통상 60분. 필드 = 일시(UTC)·위경도·속도·유향·GSM신호·배터리·온도. Excel/CSV→GPX Studio. QC = SD 버퍼 포인트 시간순 재정렬. GPS 정확도 미기록. [출처확인]
- **핵심수치:**
  - **총 14기 / 5회, 2021-04~12** [출처확인]
  - **본문 실측 최장 852.59km / 42.83일(2021-04-16 목판)** [출처확인]
  - 샘플링 통상 60분 [출처확인]
  - **"2,845km / 94일"(초록)** — 본문 852.59km와 3.3배 불일치 + Duncan B2와 동일 → **폐기, 절대 사용 금지** [출처불명·표시필수]
- **출처:** [Sensors 23(2):935 (PMC9863889)](https://pmc.ncbi.nlm.nih.gov/articles/PMC9863889/) · [DOI 10.3390/s23020935](https://doi.org/10.3390/s23020935)
- **자료 없음:** 유닛 제작비, MADUINO 배터리 사양, 정식 메타데이터 표준명, 개별 GPS 정확도/HDOP.

---

### Case 5 — Kang et al. 2025 제주 4하구 IoT/셀룰러 드리프터 11기 (KJRS 41(5):911)
**한 줄:** 동아대팀이 오픈소스 MCU + 다중망 셀룰러(NB-IoT/LTE-M Cat-M1/2G) + GNSS 드리프터 11기를 제주 4하구에 우기 대조기 방류, 1시간 측위·클라우드 전송, VSC + windage 계수로 "바람이 아니라 해류가 지배"함을 실증. **FF 전자스택과 사실상 동일.**

- **제작:** "오픈소스 MCU + GNSS" + "다중망 셀룰러(NB-IoT/LTE-M Cat-M1/GPRS)" + 리튬이온. **보드/칩셋 모델명·하우징·밸러스트·부력·치수·무게·원가 미공개.** ("SIMCom 기반"은 추정으로 **논문 명시 아님**.) [일부 출처확인/상세 자료 없음]
- **운영:** 2회 캠페인, 대조기+강우 동기화. 7-13~14(5기)·8-10~11(6기), 총 11기. 4하구(천미천 E·금성천 W·효돈천 S·화북천 N). KHOA 고조 시각표 동기화. **회수 절차 없음.** 1-1호 약 9시간 외해 표류 후 송신중단. [출처확인]
- **데이터:** GNSS <2.5m(CEP 50%), 1시간 샘플링. 셀룰러 클라우드 업로드, 연결 상실 시 내부저장·복구 시 자동업로드, 전송 간 슬립. 시간순 정렬+선형보간. 3시간 평균 변위 vs 6시간별 NOMADS 풍·CMEMS 유속. [출처확인]
- **핵심수치:**
  - 총 11기, 4하구 [출처확인]
  - **GNSS <2.5m CEP·1시간** — KJRS 논문 기준 [단일출처·주의]
  - **windage α: 7월 0.012±0.002 / 8월 0.014±0.003(범위 0.002~0.027)** [단일출처·주의]
  - VSC(부이 vs 해류, 7월) 0.501±0.209 [단일출처·주의]
  - 1-1호 약 9시간 후 송신중단 [출처확인]
  - **OpenDrift 미사용**(VSC + windage) — 병기 필수
- **출처:** [KJRS 41(5):16](https://www.kjrs.org/journal/view.html?doi=10.7780/kjrs.2025.41.5.16) · [KoreaScience 미러](https://koreascience.kr/article/JAKO202532336057759.page)
- **자료 없음:** 하우징·밸러스트·부력·치수·무게, 원가, MCU/모뎀 정확 모델(SIMCom 추정), 배터리 용량, 회수 절차, 정식 메타데이터 표준.

---

### Case 6 — 한강하구 2025 GPS 드리프터 49기 (Do et al., Marine Pollution Bulletin Vol.222, Art.118670, 2026; 인하대 우승범 연구실)
**한 줄:** 인하대팀이 강화도 인근 한강하구 3개 정점에 GPS 드리프터 49기를 6개월 방류한 라그랑주 추적 연구. **단, 3축 세부(기구·통신·샘플링·데이터포맷·회수)는 페이월 본문에만 있어 공개 확인 불가.**

- **제작:** **공개출처(초록/CrossRef)에 재료·전자·하우징·밸러스트·부력·원가·제작주체 모두 없음.** [자료 없음]
- **운영:** (초록 주장) 49기·3정점·6개월, 좌초-재부유 반복으로 한 달+ 체류. **회수 여부·방법·방류 프로토콜 초록에 없음.** [자료 없음]
- **데이터:** (초록 주장) GPS 라그랑주 궤적으로 체류·탈출률·좌초/재부유·유속 산출. **측위 모듈·통신·샘플링·포맷·메타데이터·QC·보정 공개출처에 없음.** [자료 없음]
- **핵심수치(모두 페이월 초록 귀속):**
  - 49기 / 3정점 / 6개월 — CrossRef로 저자·DOI·권호(MPB Vol.222, Art.118670, 2026-01) 교차검증, 규모 자체는 [단일출처·주의]
  - **탈출 약 12% / 좌초 후 절반 이상 3일 내 재부유 / 체류 1개월+ / 탈출유발 일유량 상위 5% / 대조기 유속 소조기 대비 약 2배** — **논문 초록 주장, 공개 재확인 불가(재검증 시 403 페이월)** [출처불명·표시필수]
  - **"강화도 해양쓰레기 수거량 전국 2위(1위 제주 차귀도)"** — **제공 출처 어디에도 근거 없음. 별도 수거통계 출처 없이 사용 금지(출처 미확인)** [출처불명·표시필수]
- **출처:** [ScienceDirect 초록(403)](https://www.sciencedirect.com/science/article/abs/pii/S0025326X25011464) · [CrossRef DOI](https://api.crossref.org/works/10.1016/j.marpolbul.2025.118670)
- **주의:** 검색에 나온 "원통 25cm×7cm·5분 샘플링·상단 GPS·10m·배터리 2~3개월"은 fetch가 "유사 연구"로 명시 → 본 논문 귀속 아님.

---

### Case 7 — PlasticPirates Europe + Precious Plastic (시민과학 운영/거버넌스 2종)
**한 줄:** 둘 다 "중앙이 표준·검증을 쥐고 제작·현장은 완전 분산" 모델 — PlasticPirates는 표준 프로토콜+실물 회수 검증으로 학생 데이터를 과학데이터로 승격, Precious Plastic은 CC BY-SA 오픈하드웨어+Bazar 마켓으로 저가 기구를 전세계 복제·자립하게 한다.

- **제작:** PlasticPirates — 코어(채집망 mesh)만 주문폼 공급, 나머지 자작. 부력=물 절반 채운 1.5L 페트병 2개를 케이블타이로 망 양옆 고정, 로프 최소 8mm·10m. **현장 밸러스트 튜닝 명시:** "물에 던져 절반 잠기면 OK, 아니면 페트병 물 가감." Precious Plastic — CC BY-SA 4.0 도면·CAD·영상 공개, 4대 기계, "loose design"(부품 편차 흡수). [출처확인]
- **운영:** PlasticPirates — 4역할 분업(A 정량 / B 수거·분류 / C 채집망 / D 사진검증), 그룹C **정확히 60분 방류**, 유속=강변 20m 표류시간, 코디네이터 전회차·약 20분 브리핑·판독확인. Precious Plastic — 파견 없음, Bazar 자립, 2~3년 리디자인(v1 2013→v4 2020). [출처확인]
- **데이터:** PlasticPirates — 수기 GPS·종이시트→웹포털 수동업로드, 이벤트 기반(60분·30분). 없으면 반드시 0 입력. **핵심 QC=이중검증**(그룹D 사진 대조 + 채집망 실물 라벨 반송→연구팀 재분석). FAIR+Zenodo(CC BY 4.0)·EMODnet. Precious Plastic — 산출물=설계·문서, CC BY-SA 4.0. [출처확인]
- **핵심수치:**
  - 채집망 방류 정확히 60분, 유속 20m 구간, 로프 8mm·10m [출처확인]
  - 입자 클래스 메조 24.99~5mm / 마이크로 4.99~1mm / macrolitter >5mm [출처확인]
  - **참여 "학생 25,000명+·14개국·390곳", "데이터셋 1,200+건·하천 360곳+"** — Horizon/CINEA 홍보성 집계 [단일출처·주의]
  - **Precious Plastic 기계 원가 Shredder~£200 / Extrusion~£200 / Injection~£120 / Compression~£120** — RPi 매거진 추정, **범위로만** [단일출처·주의]
  - **커뮤니티 규모 = 범위로만**(작업공간 200~400+·참여자 40,000~100,000) [단일출처·주의]
- **출처:** [Group C 체크리스트 PDF](https://www.plastic-pirates.eu/sites/default/files/document/2023-09/Checklist_GROUPC_EN.pdf) · [CINEA](https://cinea.ec.europa.eu/featured-projects/plasticpirates-empowering-citizen-science-tackle-plastic-pollution_en) · [Kiessling et al.](https://www.sciencedirect.com/science/article/pii/S004896972102920X) · [Precious Plastic, Wikipedia](https://en.wikipedia.org/wiki/Precious_Plastic) · [RPi Magazine](https://magazine.raspberrypi.com/articles/precious-plastic-machines)
- **자료 없음:** 채집망 정확 메시(약 1mm급 추정), 대형쓰레기 구간 표준 길이(100m 미확증), Precious Plastic 단일 확정치, 두 사례 모두 통신·자동측위 선례 없음.

---

### Case 8 — 홍콩 Marine Litter Detective (WWF-HK · MakerBay · Seeed, 2021~)
**한 줄:** 밀랍+티슈 복합(생분해) 하우징 + Arduino Pro Mini + SIM808(2G GSM/GPRS+GPS) 저가 드리프터를 **학생이 제작해 11개 학교·110대**(10대/교·2~3명당 1대)로 홍콩 우수관·하천·바다에 방류, MySQL+PHP+**Leaflet 실시간 지도**로 시각화한 **학교 시민과학 최대 배치** — FF 교육시장 모델의 직계 선례이나, 2G·저사양 MCU·미표준화는 반면교사.

- **제작:** MCU **Arduino Pro Mini 3.3V**(ESP32 아님·저사양). 측위/통신 Seeed **"LoNet 808"(SIM808) = 2G GSM/GPRS + GPS** + Seeed 커스텀 PCB. 하우징 **밀랍(파라핀) + 티슈페이퍼 복합**("코코넛 착안") — **한 소재가 방수와 부력을 동시** 담당, 생분해 지향. **재료비 500 HKD 미만(약 60 USD/55 EUR)** all inclusive. 학생 조립 가능. [출처확인]
- **운영:** 홍콩 우수관(storm drain)·하천·바다 방류, **11개 학교·10대/교·2~3명당 1대**로 학생 제작·배치. "쓰레기가 우수관·하천을 통해 바다로 드는 경로" 모사. **회수 = 발견자가 WWF 이메일로 연락**하는 습득 신고 방식(우리 found.html QR과 동일 계보) — 체계적 회수는 아님. [출처확인]
- **데이터:** GPS 측위 → **2G(GSM/GPRS)로 FTP/HTTP 전송 → MySQL 백엔드**, PHP로 JSON/CSV 추출 → **Leaflet "Ocean Litter Real-time Map"**. 하드웨어·소프트웨어 **전부 오픈소스**(GitHub MakerBay/Marine_Litter_Detective · makerbay.github.io · marinelitterdetective.net). 샘플링 주기·QC·메타데이터 표준 비명시. [출처확인]
- **핵심수치:**
  - **총 110대 = 10대 × 11개 학교, 2~3명당 1대** [출처확인]
  - 재료비 **<500 HKD(약 60 USD/55 EUR)** all inclusive [출처확인]
  - 일부 유닛 **약 1,000km/1개월(대만까지)** 표류 [단일출처·주의] — 단일물체·해상 최대치이므로 대표성 아님(Duncan/Merlino 폐기값 교훈과 동일 규율)
- **출처:** [Seeed Studio 블로그](https://www.seeedstudio.com/blog/2022/01/11/open-source-gears-to-conserve-the-marine-ecosystem-hong-kongs-marine-litter-detective-project-developed-by-makerbay-wwf-s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) · [MakerBay GitHub](https://github.com/MakerBay/Marine_Litter_Detective) · [프로젝트 페이지](https://makerbay.github.io/Marine_Litter_Detective/) · [marinelitterdetective.net](http://marinelitterdetective.net/) · [WWF-HK](https://www.wwf.org.hk/)
- **자료 없음:** 배터리 사양, 밀랍 하우징 방수 지속·열 취약(용융)·수명, 정확 방류 일자·회수율, GPS 정확도/샘플링 주기, 궤적 QC·메타데이터 표준, ECF 예산 규모.
- **★교훈·반면교사(심층):**
  - **교육 페다고지 실증:** 10대/학교·**2~3명당 1대** = 소그룹 핸즈온 설계 수치. FF 교육 모듈(학급당 대수·조 편성)에 직접 이식. 학생 제작 110대·11학교 = 오픈소스 학교 배치 최대 규모.
  - **단일소재 방수+부력(밀랍+티슈)의 우아함과 양날:** 한 소재가 두 기능 → 초저가·조립 단순. 그러나 방수 지속·열 용융·내구·회수성은 PET+EVA+씰 대비 불리. FF는 회수-우선이라 내구·씰 유지하되, 밀랍형을 **원거리·소모형 생분해 변형**의 선택지로 문서화 가능.
  - **저사양 MCU(Arduino Pro Mini)의 한계:** 버퍼 여유가 적어 **store-and-forward(음영구간 버퍼 후 재전송)** 구현이 빈약해지기 쉽다 → FF의 **ESP32-WROVER + RTC 버퍼**가 하천 교각 음영 데이터 손실을 줄이는 이유.
  - **2G 의존 = 최대 반면교사:** SIM808은 2G. 한국(2G 종료)·일몰 국가 재현 불가 → FF **Cat.1 정당성**.
  - **미표준화가 확산을 막았다:** MySQL+PHP+Leaflet 스택은 훌륭하나 **교차 비교 가능한 데이터 스키마 부재** → [왜_공백이_존재했나](왜_공백이_존재했나_한계_반면교사.md)의 "각자 스택·표준 없음→무브먼트 실패"의 실례. FF의 기여점(FF-ID 표준)이 이 공백을 메움.
  - **회수 경로 = found.html 검증:** 발견자→기관 이메일 신고 = 우리 습득신고 페이지(uploads.caresea.kr/seacut/found)와 동일 발상. 선례가 우리 설계를 뒷받침.

---

## 2. ★ 3축 비교표

| 사례 | 기구체 제작 | 운영 실험 | 데이터 기록 |
|---|---|---|---|
| **1. NOAA GDP** | 구형 30.5~40cm 부표 + 15m 드로그, **항력비 약 40**(물 따라감), ABS·방오·자석. 원가 5,475→1,750 USD[단일] | 선미 투하·항해 중 가능, **미회수·death code**, 658기/년[단일], 수명 약 400일[단일] | Argos 150~1000m→GPS 10m/Iridium, 90초, **2단계 4σ QC**, 6h 크리깅, **메타디렉토리·율리우스일**, CF NetCDF[출처확인] |
| **2. OpenMetBuoy** | **통합 캐리어보드**, 조립 0.5h, 스티로폼+볼트 킬, IP68, MIT. BOM 562 USD[단일] | 검증 4배치→70궤적+, **상용 Spotter 교차검증**, 미회수[출처확인] | GNSS 30분·파랑 2h, **엣지처리**, 바이너리 버퍼·무손실 재전송, 3σ QC, 공개 디코더[출처확인] |
| **3. Duncan 2020** | **500mL PET병**+ABS, O링+에폭시, 배터리 저·중앙 밸러스트. 원가 미공개[자료없음] | 25기(GSM10+위성15), **미회수**, **하천 좌초율 약 40%**[출처확인] | GPS 3~4h, GSM/Argos, WGS84·시계재동기, Excel→ArcMap→R/sf[출처확인] |
| **4. Merlino 2023** | **고교생 제작**, 목판/절단 페트병, **몸체 50% 수면하**, 태양광[출처확인] | Arno 14기·5회, **QR 시민회수·재사용**, 여름 수시간 좌초[출처확인] | GSM 60분 + **SD 폴백**, UTC·위경도·속도·유향·신호·배터리·온도, **버퍼 재정렬**→GPX[출처확인] |
| **5. Kang 2025** | **FF 스택과 동일**(오픈MCU+GNSS+다중망 셀룰러+리튬), **재료·원가 전부 미공개**[자료없음], SIMCom 추정 | 4하구 11기, **대조기+강우·KHOA 동기화**, 회수 없음, 1기 실종[출처확인] | GNSS<2.5m·1h, 셀룰러+**오프라인 버퍼 자동업로드**, 선형보간. **OpenDrift 미사용**[출처확인] |
| **6. 한강하구 2025** | **공개출처에 없음(페이월)**[자료없음] | 49기·3정점·6개월(초록), **회수 미기재**[출처불명] | GPS 라그랑주(초록). 측위·통신·샘플링·QC **공개출처에 없음**[자료없음] |
| **7. PlasticPirates / Precious Plastic** | 물 채운 페트병 부력+**현장 밸러스트 튜닝**; PP=CC BY-SA·loose design[출처확인] | **4역할 SOP·60분 방류·코디QC**; PP=분산자립·Bazar[출처확인] | 수기 GPS·종이시트·**이중검증(사진+실물반송)**·0입력·FAIR/Zenodo. **통신·측위 선례 없음**[출처확인] |
| **8. Marine Litter Detective(홍콩)** | **밀랍+티슈 생분해**, Arduino Pro Mini+SIM808(**2G**)+GPS, <500HKD, **학생 제작**[출처확인] | **11학교·110대**(10/교·2~3명당1대), 우수관·하천·바다, **발견자 WWF신고 회수**[출처확인] | 2G→MySQL/PHP, **Leaflet 실시간지도**, **전부 오픈소스**[출처확인] |

---

## 3. ★ Friendly Floaty가 배울 것

### 제작 교훈
1. **항력비를 1급 스펙으로 두되 SVP를 반전하라.** SVP는 항력비 약 40으로 수중 15m 드로그를 따라간다. FF는 수면 쓰레기 자체가 바람·표층류로 움직이므로 **낮은 항력비(수면 추종)** 로 설계하고 **15m holey-sock 복제 금지**. [Case 1]
2. **통합 단일보드 철학 계승.** OMB의 Artemis 통합보드 = FF의 T-A7670G(ESP32+LTE+L76K 통합). 추가 센서는 Qwiic/I2C 모듈러. [Case 2]
3. **로우테크 부력·밸러스트 이식.** OMB 스티로폼+볼트 킬, Duncan 배터리 저·중앙(자기복원), Merlino "50% 수면하", PlasticPirates "물 채운 페트병 흘수 튜닝". → 조립서에 **"물에 띄워 절반 잠기면 OK, 아니면 물 가감"** + **18650 저·중앙 킬 + 방류 전 전복복원 수조시험** 표준화. [Case 2·3·4·7]
4. **좌초-재부유 견디는 얕은 흘수.** 조간대 반복 좌초에 대비, **강성 킬 금지·얕은 흘수로 조위 상승 시 자가 재부유**. [Case 5·6]
5. **안테나·씰이 생사를 가른다.** Duncan 최대 실패는 안테나 개구부 에폭시 열화. L76K+A7670G 안테나는 **건조 상단부** 배치·씰 과설계·방류 전 침수 자가시험. 하우징이 부유물·거품에 잠기지 않게 높이·무게중심 설계. [Case 2·3]
6. **글로벌 복제성 = 대체 BOM 문서화.** Precious Plastic "loose design"처럼 LILYGO·18650 대체 부품 BOM·허용 오차 명시. 코어(FF-ID·펌웨어·PCB)는 중앙 표준, 하우징·부력체는 현장 자작. [Case 7]
7. **미공개를 차별점으로.** Kang·한강하구가 원가·하우징·밸러스트를 감춘 재현성 공백을, FF는 **전부 공개**해 메운다. [Case 5·6]

### 운영 교훈
8. **검증 배치 → 대량 방류 2단계.** 소수·다정점·다계절이 단발 대량방류보다 물리해석에 유효. 괴정천/학장천 PoC 검증 후 시민 대량 방류. [Case 2·5·6]
9. **death code 규율.** FF-ID별 운명(좌초/습득/중단) 기록 없이는 하천→바다 통계가 무성실 손실로 편향. [Case 1]
10. **미회수 전제 + 명시적 회수 설계 병행.** 고손실·좌초를 예산에 반영하되, 회수형이면 **QR 라벨·최종위치 비컨·현상금·격자수색** 사전 설계. [Case 1·3·4·6]
11. **방류 타이밍·조석 동기화.** KHOA 고조표 동기화, 강우 첨두 집중관측(한강하구 초록 주장), 대조기 vs 소조기 분리 방류로 조석 의존성 측정. [Case 5·6]
12. **시민 방류 SOP.** 4역할 분업(방류·회수·GPS로그·사진검증) + 코디네이터 전회차·브리핑·판독확인. [Case 7]
13. **상용/모델 교차검증.** 상용 GPS 부이 또는 OpenDrift와 병행 비교(OMB↔SOFAR Spotter). [Case 2]
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

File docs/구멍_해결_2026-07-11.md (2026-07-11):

# 구멍 해결 보고서 (2026-07-11) — 조사·초안 7건

> 구멍 목록(docs/구멍_목록.md)의 조사·초안형 공백 7건을 전문 조사로 해결하거나 실행 직전까지 준비한 결과. 각 항목의 결론은 상단 표에, 근거·초안은 본문에. **법·행정 항목은 내부 검토용이며 최종은 기관/전문가 확인 필요**(정직 원칙).

| 구멍 | 판정 |
|---|---|
| A2 | 해결됨 |
| A3·A5 | 해결됨 |
| 구멍 B1 | 해결됨 |
| B4 | 해결됨/부분해결: 권장 보험 경로(1365 수요처 등록 → 자원봉사종합보 |
| B5 | 해결됨 |
| B7 | 해결됨 |
| B2 | 해결됨 |

---

# 구멍 A2 확정 — L76K GPS 전원 레일 회로도 분석 (T-A7670X R2)

**결론: GPS-first 펌웨어 순서(모뎀 PWRKEY 없이 GPS fix)는 회로상 성립한다 — YES.**
단, 정확히는 "GPIO12가 켜는 DC-DC/부스트"(①)가 아니라, **ESP32측 3.3V LDO 출력(VDD3V3)을 GPIO12(또는 USB VBUS)로 스위칭한 V3V 레일**이다. 모뎀 A7670의 VDD_EXT(②)도, 상시 배터리 레일(③)도 아니다.

## 1. 조사 대상 (공식 1차 자료)

LILYGO 공식 저장소는 `Xinyuan-LilyGO/LilyGO-T-A76XX` → 현재 **`Xinyuan-LilyGO/LilyGo-Modem-Series`** 로 통합·리다이렉트됨. 사용 파일:
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

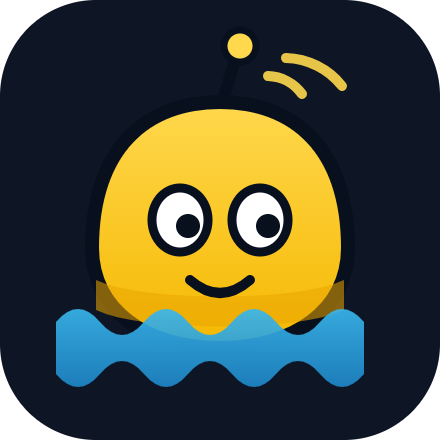
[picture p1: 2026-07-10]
brand/friendly-floaty-mark.png

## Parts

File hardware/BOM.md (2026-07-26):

# Bill of Materials (BOM)

Parts by function and generic spec first, then a globally shipping reference part, then local substitution. Prices are rough retail USD and vary by country. Full context and regional tables: [../docs/OPEN_HARDWARE_BOM_global.md](../docs/OPEN_HARDWARE_BOM_global.md).

Reference board is the LILYGO T-A7670G R2 with onboard L76K GNSS. It is cellular (LTE Cat.1 bis) plus a separate GPS chip. It is not satellite. Do not substitute the SIM7080G (LTE-M/NB-IoT), which has no verified attach on Korean commercial networks.

## Tier 0 — Phone-in-a-Bottle (USD 5–35)

| Function | Generic spec | Reference | Local substitution | ~USD |
|---|---|---|---|---|
| Compute + GPS + modem | old Android phone with GPS and 3G/4G | reused phone | any working phone, ideally reused e-waste | 0–30 |
| Logger / uplink | app that POSTs GPS to a URL | GPSLogger (open source) | any GPS logger with custom URL POST | 0 |
| SIM | prepaid data SIM | local data SIM | global IoT SIM (1NCE / Soracom) | 5–15 |
| Housing | RF-transparent float, sealed | upcycled PET bottle + dry bag | any clear plastic bottle | 0–5 |
| Ballast + visibility + recovery | bottom weight, bright tape, contact label, loop | sinker + tape + QR | any dense non-toxic weight | 2–5 |

## Tier 1 — Cellular Bottle (default, USD 50–70)

| Function | Generic spec | Reference | Local substitution | ~USD |
|---|---|---|---|---|
| Compute + modem + GPS | ESP32 + LTE Cat.1/Cat.1 bis + onboard GNSS | LILYGO T-A7670G R2 "With GPS (L76K)" — ★pick the **A7670G (2G 4G)** variant, not "4G No SMS"; ★the A7670 **modem has no GNSS**, so "with GPS" simply means an L76K chip wired to the ESP32 UART. If that variant is out of stock, a "Without GPS" board **+ a separate UART GNSS module** is the same architecture — wiring, the critical power-gating rule, and the extra gates are in [GPS_MODULE_WIRING.md](GPS_MODULE_WIRING.md) | ESP32 + A76xx board with real GNSS; pick A7670 band variant for your region | 27–33 |
| Battery | protected 18650, verify holder length | quality protected 18650 | any protected 18650 | 5–8 |
| SIM | global IoT roaming SIM or local data SIM | 1NCE 10-yr prepaid / Soracom | local data SIM | 5–14 |
| Antennas | LTE + GNSS, kept above water | board-included uFL antennas | extend outside if sealing | 0–8 |
| Housing | RF-transparent float, sealed, antenna above waterline | upcycled PET bottle | any clear plastic bottle | 0–5 |
| Ballast (self-righting) | low weight so antenna rights up | sinker at belly + printed keel | any dense non-toxic weight | 2–5 |
| Sealant | marine/silicone sealant + grommet | marine silicone | any waterproof sealant | 3–8 |
| Visibility + recovery | bright tape, waterproof QR/contact label, loop | tape + QR + paracord | local equivalents | 2–5 |
| Printed inserts | bracket + keel + loop | `cad/*.scad` | print locally | 1–3 |

## Tier 1.5 — Solar-assisted (long-dwell / recovery-insurance, +USD 15–25 over Tier 1)

For missions where a unit **dwells in-coverage for weeks** (estuary retention — the Han-estuary study shows most litter lingers 1 month+), a battery-only unit dies before it can be recovered. Add **wrap-around thin-film solar** to extend reporting life so the unit stays trackable and recoverable. ★**Solar extends power, not coverage** — a unit that leaves cellular range goes silent regardless of charge (that is satellite / Class 3). Not for short recover-in-days missions (use Tier 1). Full spec, the self-righting-preserving design, and the extra bench gates (G5 solar harvest, T7 self-right with cells): [TIER1_5_SOLAR_DRIFTER.md](TIER1_5_SOLAR_DRIFTER.md).

| Function | Generic spec | Reference (orderable) | ~USD |
|---|---|---|---|
| Solar cells | flexible thin-film, **Vmp ≈ 5 V, Voc ≤ 6 V** (★a 6 V-*nominal* a-Si panel's ~7.5 V open-circuit overshoots a CN3065 linear charger's 4.4–6 V input window and stalls in low light — check the panel datasheet, not just the marketing "6 V"), min-bend-radius ≤46 mm. ★**Non-metal RF-transparent substrate only** — a-Si (ETFE front) or Cd-free CIGS (polyimide); no stainless-backed CIGS / CdTe / perovskite (RF shield + toxicity) | PowerFilm-class flexible a-Si panel (ETFE front) | 8–15 |
| Charge control | ★**external low-Iq linear (default) to the BATTERY terminal**, zip-tied to the existing bracket; onboard-direct only a small-panel exception (buck-boost to 5.0–5.2 V); MPPT for clean/summer sites | CN3065 breakout module (linear) / CN3791 (MPPT) | 0–10 |
| Low-temp cutoff | ★**mandatory all modes, hardware latch** — <0 ℃ charge blocked (not firmware) | 10 kΩ B3435 NTC epoxy-bonded to the cell can | 0.5 |
| Isolation diode | reverse-block the panel | Schottky / ideal-diode module | 0.5 |
| Vent | pressure/heat equalise — **not** a printed boss | Gore-Tex ePTFE adhesive vent patch | 2–4 |
| Extra foam | buoyancy re-cut, ★**density-aware +6.7 cm³/10 g** (panel ρ≈1.64, NOT the ballast 11.7) | closed-cell EVA sheet | ~1 |
| Battery (optional 2nd) | ★**matched + isolation diode/balancing**, belly placement; else one larger protected cell | matched protected 18650 | 8–11 |

Everything else is identical to Tier 1. Keep the battery sized to survive the planned dwell on its own; solar is margin, not a design input, until bench G5 measures real harvest.

## Tier 2 — Reusable Robust (upgrade, USD 90–130)

Adds on top of Tier 1: bolt-sealed IP-rated opaque enclosure with gasket, IP-rated cable glands, external waterproof antennas via bulkhead, temperature-protected charging (NTC/JEITA) for cold water, bulk capacitor plus supercap for the modem's ~2 A transmit peak, printed internal frame, cell-failure containment. Use only for repeated, cold, or harsh campaigns. Power sizing and the reliability rationale for these additions: [ELECTRONICS_POWER.md](ELECTRONICS_POWER.md) and [RELIABILITY.md](RELIABILITY.md). A field-validated, fully costed robust build is pending first deployment — this repo publishes the reference design, not a proven 50-unit run.

## Notes (all cellular tiers)

- The board's GNSS is a separate L76K chip read over its own UART (NMEA via TinyGPSPlus), not the modem's AT GNSS.
- Firmware library must be lewisxhe/TinyGSM-fork; stock TinyGSM lacks the A7670 macro.
- Always test with the battery installed. USB-only power browns out on the transmit peak and looks like a modem fault.
- Housing must be non-metallic and the antenna must stay above the waterline, or GPS and cellular both die.
- Power budget (ping interval vs 18650 endurance), mission device-classes (river / estuary / open-ocean), and the solar option: see [ELECTRONICS_POWER.md](ELECTRONICS_POWER.md). Battery-only + recover-to-recharge is the default. Solar comes in two documented forms: a **fixed Tier-3** station and a **long-dwell drifter [Tier 1.5](TIER1_5_SOLAR_DRIFTER.md)** — neither is the short-mission baseline.

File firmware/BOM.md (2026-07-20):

> # ⛔ DEPRECATED — 이 표대로 구매하지 마세요
> 이 파일은 초기 탐색안이며 **현행 정본 [`hardware/BOM.md`](../hardware/BOM.md)와 충돌**합니다. 그대로 사면 **배포 불가 + 발화 위험**에 동시에 걸립니다:
> - **모뎀 SIM7080G(LTE-M/NB-IoT) = 국내 상용망 attach 미검증**(현행 리포가 명시 금지). 정본 모뎀은 **LILYGO T-A7670G R2(LTE Cat.1)**.
> - **태양광 충전 TP4056 = 저온 충전차단 없음** → 겨울 밀폐 병 속 리튬 저온충전 = **발화**. 정본은 **CN3065 + B3435 NTC 하드웨어 저온 컷오프**([`hardware/TIER1_5_SOLAR_DRIFTER.md`](../hardware/TIER1_5_SOLAR_DRIFTER.md)).
> - **"주간 충전 → 사실상 무한 / 5분 상시 운용" = 허위.** 5분 핑은 오히려 최다 소비 구간(≈4일)이다. 정직한 전력 예산은 [`hardware/ELECTRONICS_POWER.md`](../hardware/ELECTRONICS_POWER.md).
>
> **구매·조립은 오직 `hardware/BOM.md`를 정본으로 쓰세요.** 이 파일은 이력 보존용으로만 남깁니다.

---

# SEA:CUT 드리프터 부품표(BOM) — ESP32 + GPS + LTE-M  〔DEPRECATED·아래 내용 신뢰 금지〕

간헐 전송("fix→POST→sleep") 드리프터 1대 기준. 가격은 국내 소매 대략치(원).

## 핵심 전자부

| 부품 | 예시 모델 | 단가(원) | 비고 |
|---|---|---|---|
| MCU | ESP32 (베어 모듈 권장, 데브보드는 시연용) | 4,000~7,000 | deep sleep 10µA대. NodeMCU 데브보드는 기생소모 큼 |
| GPS 모듈 | u-blox NEO-6M / NEO-8M | 6,000~12,000 | UART. 백업전원으로 핫스타트 절약 |
| 셀룰러 모뎀 | SIMCom SIM7080G (LTE-M/NB-IoT) | 12,000~22,000 | 게이트웨이 불필요. PSM 저전력 |
| USIM | 통신사 IoT 요금제 | 월 2,000~4,000 | SKT/KT LTE-M |
| 전원 게이팅 | P-ch MOSFET + 저항 | 1,000 | GPS·모뎀 슬립 시 완전차단 |
| 배터리 | 리튬 18650 2,000~3,000mAh | 3,000~6,000 | 방수 홀더 |
| (선택) 태양광 | 5V 1~2W 소형 패널 + TP4056 | 5,000~9,000 | 주간 충전 → 사실상 무한 |
| 안테나 | GPS 액티브 + LTE 안테나 | 3,000~6,000 | ★수면 위로 노출 필수 |

**전자부 소계: 약 3.3만~6.9만원/대** (태양광 포함 시 상단).

## 하우징·부력

| 부품 | 비고 | 단가(원) |
|---|---|---|
| 방수 케이스 | IP68, 안테나 관통부 방수 | 5,000~15,000 |
| 부력체 | 폐부표재 재활용(사업 컨셉과 정합) | 재활용 0~ |
| 무게추·날개 | 흘수 조정(수면상 최소·수면하 최대) | 2,000~ |
| (선택) 생분해 프레임 | 유실 시 환경부하 저감 | 별도 |

## 총계

- **전자부 + 하우징: 대당 약 8만~15만원** (수량·태양광·케이스 등급에 따라).
- 앞서 조사한 독일만 컴팩트 드리프터($300)에서 위성을 LTE-M으로 대체해 절반 이하.

## LoRa 대안(참고)

| 항목 | LTE-M(본 BOM) | LoRa |
|---|---|---|
| 모뎀 단가 | 1.2~2.2만 | 0.4~0.8만 (더 쌈) |
| 인프라 | 불필요(기지국) | ★게이트웨이 필요 3~15만/대 + 설치 |
| 통신비 | 월 소액 | 0(자체 게이트웨이) |
| 적합 | 소수·연안·PoC | 게이트웨이 1대 + 드리프터 대량 |

소하천 PoC는 LTE-M 권장. 붐 고정 구역에 게이트웨이 세우고 대량 운용하는 단계에서 LoRa 전환.

## 통신 요건

- 낙동강 하구·연안은 LTE 커버리지 안 → 위성 불필요.
- 안테나는 반드시 수면 위. 물에 잠기면 GPS·LTE 둘 다 죽음.
- 전송 주기 5분이면 태양광 소형 패널로 상시 운용 가능.

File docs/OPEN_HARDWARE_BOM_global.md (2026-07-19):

# SEA:CUT / Friendly Floaty — Global Onboarding & Regional Selection

An open-source, non-profit river-to-sea litter drifter: a low-cost GPS + cellular float you release into a river, track from anywhere, and **recover**. It maps how floating trash travels from source to sea so communities know where to place booms and cleanups.

This is a movement, not a product. In the spirit of Precious Plastic, we publish the design so anyone, anywhere can build one from locally available parts, adapt it, and share the data. We do not ship certified finished units. You build, you own your deployment, you follow your local rules. What keeps that trustworthy is not the absence of caveats but a few strong, universal ones (Section 1).

**This page is the international companion to the canonical build docs — it does not restate them.** Read it for the ethic, how it works, and how to pick a radio/SIM/site for *your* country. For the actual parts list, the data format, and the field procedure, follow the single sources of truth:

| You want… | Canonical source (do not duplicate) |
|---|---|
| Parts list by tier (with local substitutions) | [../hardware/BOM.md](../hardware/BOM.md) |
| Data format (FF-ID v1.1) | [../data/schema.md](../data/schema.md) |
| Reference firmware | [../firmware/drifter_a7670_cat1/](../firmware/drifter_a7670_cat1/) |
| Ingest server | [../server/README.md](../server/README.md) |
| Float physics & hard gates | [../hardware/FLOAT_STANDARD.md](../hardware/FLOAT_STANDARD.md) |
| Build variance across countries | [DIY_DIVERSITY.md](DIY_DIVERSITY.md) |
| Deploy responsibly (localize) | [DEPLOY_responsibly.md](DEPLOY_responsibly.md) |

Licenses: firmware **MIT** · hardware design **CERN-OHL-S** (strongly reciprocal, see [../LICENSE-hardware.md](../LICENSE-hardware.md)) · documentation **CC BY-SA 4.0** · observation **data CC BY 4.0** (permissive, so pooled citizen-science data combines and cites freely). See [../LICENSE-docs.md](../LICENSE-docs.md).

---

## 1. The four rules that travel with the design

Precious Plastic did not spread by ignoring safety. It spread because it paired open designs with a handful of simple, non-negotiable rules (ventilate, never burn) and pushed everything else to the local operator. These are ours. They are values, not regulations, and they are what make the open-source spread credible instead of reckless.

1. **Recover what you release.** This is a marine-litter project. A device left in the water is the exact problem we fight. Design every unit for recovery (high visibility, contact label, a grab loop), track it, and go get it. If you cannot recover it, do not release it. Recovery is not a rule imposed on us — it is our identity.
2. **Safe power, no toxics.** Use a protected Li-ion cell. Do not charge below 0 °C or let the enclosure cook above 45 °C. Contain a single-cell failure. No burning, no toxic materials, non-metallic RF-transparent housing. Account for the device's own footprint.
3. **Do no harm to the water or its users.** Smooth shapes that will not entangle wildlife or snag nets and propellers. Avoid protected or sensitive areas and breeding seasons unless locally cleared. Tell nearby water users you are there.
4. **Own your deployment, follow your local rules.** Releasing into shared water and transmitting on cellular or radio is regulated differently in every country. We give you the design; the deployment is yours. Start tiny (a few units), learn, then scale. Section 5 is a generic localize checklist, with Korea as one worked example.

Deployments involving under-18 participants carry extra, mandatory rules — see [../SAFETY_MINORS.md](../SAFETY_MINORS.md).

---

## 2. How it works

Wake on a timer, get a GPS fix, POST one small JSON ping over the cellular network, sleep. The device sends a single coordinate; a server assembles the track. No user-built gateway or infrastructure is required — the mobile network is the infrastructure.

```
[drifter] --GPS fix--> --cellular POST--> [ingest server] --> [public map / open data]
   sleep <------------------------------------ 200 OK
```

The ping and track format is **FF-ID v1.1**, defined once in **[../data/schema.md](../data/schema.md)** (with `obs_id`, provenance, QC, and physical covariates). Do not hand-copy the JSON here — a duplicated schema drifts out of sync, which is the exact interoperability failure the standard exists to prevent. Run your own ingest server ([../server/README.md](../server/README.md)) or POST to a shared community endpoint. Data belongs to the community under **CC BY**.

---

## 3. Choose your tier (concept)

Pick the lowest tier that answers your question. A river survey with a handful of floats does not need the robust tier. Start cheap, prove the pipeline, then scale.

- **Tier 0 — Phone-in-a-Bottle** (~USD 5–35): a reused smartphone + a GPS-logging app in a sealed bottle. Proves the whole chain (device → server → map) for almost nothing, anywhere, from e-waste. Use it first.
- **Tier 1 — Cellular Bottle** (~USD 50–70, **the movement default**): an ESP32 cellular board inside an upcycled PET bottle. The most diffusible, the cheapest that still runs unattended, and it is literally the litter it studies.
- **Tier 1.5 — Solar-assisted long-dwell** (Tier 1 + a wrap-around thin-film cell): for long-dwell monitoring where recovery may take weeks — see [../hardware/TIER1_5_SOLAR_DRIFTER.md](../hardware/TIER1_5_SOLAR_DRIFTER.md).
- **Tier 2 — Reusable Robust** (~USD 90–130): bolt-sealed IP-rated case, external antennas, temperature-protected charging, self-righting keel. For repeated, cold, or harsh campaigns — not the starting point.

**The full parts list for every tier, with per-function local substitutions, lives in [../hardware/BOM.md](../hardware/BOM.md).** That is the one table to keep current; this page intentionally does not copy it.

Three notes that apply to all cellular tiers (and are enforced in firmware and CAD):
- The reference board's GNSS is a **separate L76K chip** read over its own UART (NMEA via TinyGPSPlus), not the modem's AT GNSS. That separation is the whole point — GPS runs with the modem asleep, which is what makes store-and-forward battery life possible. The firmware library must be **lewisxhe/TinyGSM-fork** (stock TinyGSM lacks the A7670 macro).
- **Always test with the battery installed.** USB-only power browns out on the modem's transmit peak and looks like a modem fault.
- **Housing must be non-metallic and the antenna must stay above the waterline**, or GPS and cellular both die. (The solar variant adds a hard gate: a metal-substrate cell over the RF window is rejected in CAD — see FLOAT_STANDARD.)

---

## 4. Communications: pick your backhaul by region

Cellular is the simplest global option because the mobile network is already everywhere people are. Two things are regional: the LTE bands and the SIM.

Cellular board variant by region (A7670 family — pick for your bands):

| Variant | Typical LTE-FDD bands | Fits |
|---|---|---|
| A7670E | B1/B3/B5/B7/B8/B20 | Europe, Middle East, Africa, Korea, most of Asia, Australia |
| **A7670G** | global multiband (adds Americas bands, e.g. B2/B4/B12/B25/B66) | Americas and worldwide roaming — **the reference board** |
| A7670SA | Latin America bands | South/Central America |

The reference build uses the **T-A7670G R2** (global variant) to maximize band coverage. Match the variant to your carrier's bands; do not assume one variant is region-locked without checking the band list. **Do not** substitute the SIM7080G (LTE-M / NB-IoT) — it has no verified attach on Korean commercial networks.

SIM options, easiest first:
- **Global IoT SIM** (1NCE, Soracom): one SIM works across many countries; ideal for a hand-built device because it roams and sidesteps local device-registration. Confirm which local carriers it roams onto in your country (e.g. in Korea it roams on KT/SKT, not LG U+). Soracom only matters where its partner carriers have coverage — in a single-country pilot a local prepaid SIM is often simpler and cheaper.
- **Local prepaid data SIM**: cheapest per-country; confirm a hand-built (non-certified) device is allowed to attach to data.

**No cellular coverage** (remote/rural rivers)? The reference firmware is cellular-only; LoRa is a *documented alternative backhaul, not part of the reference build*. Meshtastic runs license-exempt ISM bands (868 MHz EU/Africa · 915 MHz Americas/Australia · 923 MHz most of Asia · KR920 920–923 MHz Korea) but needs one or two community gateways with line of sight. It is out of scope for this repo's firmware; follow the upstream Meshtastic project docs if you take that path.

### Cost — why an integrated board, and what satellite really costs

Two questions builders always ask. Prices are single-unit import retail (vary by country, quantity, duty, shipping).

**"Three separate parts must be cheaper than the integrated board?"** Barely — and not once it is in water:

| Approach | Part | ~USD |
|---|---|---|
| Separate | ESP32 dev board | 1–5 |
| | A7670E LTE Cat.1 module (breakout) | 14–17 |
| | GNSS module (NEO-6M / ATGM336H class) | 3–5 |
| | **subtotal** | **~21–26** |
| Integrated | LILYGO T-A7670G R2 (with GNSS) | **~27** (manufacturer store) |

The **LTE modem (~$15) is the cost floor**, not the ESP32 (~$4) — you buy the modem either way, so avoiding integration saves little. The separate route's ~$3–5 paper saving is eaten by: 3× the solder joints and connectors (each a leak/failure point in a sealed water device), 2–3 antennas sourced separately, no built-in SIM slot / power path / UART level-shifting / USB programming, more volume and mass (worse for the bottle and for self-righting), and firmware pin-maps written for the reference board. Integration is cheaper *per reliable unit*. Real savings appear only at hundreds of units on your own PCB — at which point you have re-built the integrated board yourself. (Korea: you cannot dodge the modem cost with a cheaper LTE-M/NB-IoT part — the SIM7080G has no verified attach on Korean networks.) The manufacturer's own storefront (e.g. the maker's official AliExpress store, factory-direct from Shenzhen) is typically the cheapest source; resellers add margin and local-warehouse convenience.

**"How expensive is satellite (Class 3 — open ocean beyond cellular)?"** Roughly 10× the hardware plus recurring airtime:

| Satellite path | Hardware | Airtime | Note |
|---|---|---|---|
| Myriota / Astrocast | module ~$20–40 | low subscription | **store-and-forward, not real-time** (data on satellite pass, minutes–hours late). Fine for sparse telemetry, not live tracking |
| Swarm M138 | ~$150 | ~$60/yr | was the cheap two-way, but **new-device sales halted 2023** (SpaceX) — not a path for new builds |
| **Iridium RockBLOCK 9603** | **~$250–270** | line rental **~$15/mo** + per-message credits (1 credit / 50 bytes) | **truly global incl. open ocean, real-time** SBD — the standard for ocean drifters |

Against a ~$27 cellular unit, real-time open-ocean tracking (Iridium) is **~10× the hardware plus a recurring bill**. This is exactly why the reference design targets river→coastal water inside cellular coverage and separates satellite as Class 3: cellular goes silent offshore because base stations are on land — a physics limit no cheaper board fixes, only a satellite one, at the cost above.

### Sourcing — what to import, what to buy locally

Only two parts are spec-critical to source. Everything else is generic hardware you already have locally.

- **Cellular board.** Check a local distributor first — faster, no customs, local warranty, and the seller has already cleared type-approval. If it is not sold locally, the manufacturer's own official store (e.g. their factory-direct AliExpress store) is usually the cheapest source. Express couriers (DHL/FedEx) are fast but the shipping can equal the board on a single-unit order and may add a customs-brokerage fee even under your country's duty-free threshold; standard/postal is slower but often cheaper landed. A hand-built cellular device is regulated somewhere — see [DEPLOY_responsibly.md](DEPLOY_responsibly.md); buying a locally-stocked board sidesteps the personal-import approval question.
- **Solar film (Tier 1.5 only) — the one part where a cheap local panel can silently break the design.** "Flexible thin-film" is a *form factor*, not a material, and the material decides RF and toxicity:
  - **a-Si (amorphous silicon), ETFE/plastic front — recommended.** Non-metal → RF-transparent (B5), non-toxic, cheap (small 5–6 V panels ~$5–20). The drifter's low power budget does not need high efficiency, so this is the rare case where the cheapest option is also the correct one.
  - **CIGS** — higher efficiency, but the common flexible CIGS is on a **stainless-steel** substrate (industry-standard, since CIGS needs >500 °C processing) = a metal RF shield over the antenna = disqualified. Only Cd-free CIGS on **polyimide** (non-metal) is acceptable, and it is less common and more expensive. Do not pay more for CIGS here.
  - **CdTe / perovskite — no** (toxicity / immaturity / RF).
  - Rule regardless of source: **verify the substrate is non-metal.** A steel-backed panel kills the radio even if everything else is perfect.
- **Everything else is local:** protected 18650 cell, SIM, uFL antennas, the PET bottle, ballast (a fishing sinker), marine sealant, bright tape / QR label / recovery loop, and the printed inserts (print them yourself). None need importing.

---

## 5. Deploy responsibly — localize (generic, with one worked example)

We give you the design. The release is yours. Before you put units in the water, walk this generic checklist and apply your own country's rules. This is the "attach the caveats" step that lets an open-source project spread without becoming reckless. It is a habit, not a wall. The full version, with hard gates, is in **[DEPLOY_responsibly.md](DEPLOY_responsibly.md)** and **[DIY_DIVERSITY.md](DIY_DIVERSITY.md) §4.4**.

Generic checklist (applies everywhere):
- **Radio / telecom.** A hand-built cellular or radio transmitter is regulated somewhere. Check whether your country needs a type-approval, exemption, or license for a small research/DIY transmitter, and whether your SIM/band is allowed. Global IoT roaming SIMs often simplify this.
- **Water access.** Someone manages the water you release into (municipal river, national river, protected wetland, harbor, coastal zone). Find out who and ask. Protected/heritage/wetland areas usually need extra consent, so prefer an ordinary local stream for a first pilot.
- **Battery and e-waste.** Li-ion in water is a fire and pollution risk if lost. Protect, contain, and above all recover (Rule 1). Have a plan for cells at end of life.
- **Wildlife and other users.** Smooth, non-entangling shapes. Avoid breeding seasons and protected species areas. Tell fishers, harbor authority, and coastguard so an unknown sealed electronic box washing ashore does not become an alarm.
- **Start small and honest.** A few units, recover them all, learn recovery rate and drift behavior, then size a larger release from what you measured — not from a round number.

Worked example — Korea (one locale among many):
- **Radio:** a hand-built cellular device for outdoor multi-unit use is subject to conformity assessment; obtain a research/development exemption confirmation from the national radio agency (RRA, form 12, up to 1,500 units) before releasing. A global IoT roaming SIM (KT/SKT) avoids local device-registration.
- **Water:** the Nakdong main channel and estuary are a national river plus a natural-monument/wetland protected zone (national-level consent). An ordinary tributary stream (managed by the city/district) is the low-friction pilot site and is still genuinely "source to sea" because the tributary flows to the estuary.
- The rest (battery safety, recovery-first, wildlife, notify water users) is the same universal set above.

Other countries: replace the two locale-specific lines (radio authority, water manager) with your own, keep everything else. A second worked example — warm, monsoon-driven, high-UV — is [DEPLOY_tropical.md](DEPLOY_tropical.md) (Da Nang, Vietnam). If you build one, add your locale's notes to [DIY_DIVERSITY.md](DIY_DIVERSITY.md) so the next person in your country starts faster. That is how the movement compounds.

---

## 6. Join, contribute, share data

- Build a unit, release and recover it in your river, and POST FF-ID trajectories to your own ingest server or the shared map.
- Register your variant and add your river via the issue templates (`.github/ISSUE_TEMPLATE/`); add your locale notes to [DIY_DIVERSITY.md](DIY_DIVERSITY.md).
- Improve the design: better self-righting bottle geometry, cheaper regional part swaps, translations. Open a pull request — CI parses the CAD and checks the schema/links so your change stays interoperable.
- Data is **CC BY**. Attribution: *SEA:CUT / Friendly Floaty — 사단법인 이타서울 / GAA (Global Adopt-a-Beach Alliance) and the contributor.* See [../CITATION.cff](../CITATION.cff).

Built by 사단법인 이타서울 / GAA and contributors. Inspired by the open-hardware movement, including Precious Plastic and OpenMetBuoy. This is a **reference design** — field validation and a DOI-deposited dataset are pending; all figures are estimates until bench + field measurement.

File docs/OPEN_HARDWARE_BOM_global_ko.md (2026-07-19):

# SEA:CUT / Friendly Floaty — 글로벌 온보딩·지역 선택 (한국어판)

[`OPEN_HARDWARE_BOM_global.md`](OPEN_HARDWARE_BOM_global.md)의 한국어판이다. 원문(영어)과 내용을 일치시킨다. 기술 용어와 식별자는 원어 그대로 둔다.

하천에서 바다로 가는 쓰레기의 길목을 재는 오픈소스 비영리 드리프터: 강에 띄우고 어디서나 추적하다가 **회수하는** 저비용 GPS+셀룰러 부유체다. 부유쓰레기가 발원지에서 바다로 어떻게 흘러가는지를 지도로 만들어, 지역이 어디에 붐과 수거를 배치해야 하는지 알게 한다.

이것은 제품이 아니라 운동이다. Precious Plastic의 정신처럼, 우리는 설계를 공개해 누구든 어디서나 현지 부품으로 만들고 고쳐 데이터를 나눌 수 있게 한다. 인증받은 완제품을 배포하지 않는다. 당신이 만들고, 당신의 배포를 당신이 책임지고, 당신의 지역 규정을 따른다. 그것을 신뢰할 수 있게 하는 것은 단서의 부재가 아니라 몇 개의 강하고 보편적인 단서다(1장).

**이 문서는 정본 빌드 문서의 국제 동반문서이며, 그 내용을 되풀이하지 않는다.** 원칙·동작 방식·나라별 전파/SIM/현장 선택은 여기서 읽고, 실제 부품표·데이터 형식·현장 절차는 아래 단일 정본을 따른다.

| 찾는 것 | 정본(중복 금지) |
|---|---|
| 티어별 부품표(현지 대체 포함) | [../hardware/BOM.md](../hardware/BOM.md) |
| 데이터 형식(FF-ID v1.1) | [../data/schema.md](../data/schema.md) |
| 레퍼런스 펌웨어 | [../firmware/drifter_a7670_cat1/](../firmware/drifter_a7670_cat1/) |
| 수신 서버 | [../server/README.md](../server/README.md) |
| 부유 물리·하드 게이트 | [../hardware/FLOAT_STANDARD.md](../hardware/FLOAT_STANDARD.md) |
| 나라별 빌드 변주 | [DIY_DIVERSITY.md](DIY_DIVERSITY.md) |
| 책임 있는 배포(localize) | [DEPLOY_responsibly.md](DEPLOY_responsibly.md) |

라이선스: 펌웨어 **MIT** · 하드웨어 설계 **CERN-OHL-S**(강한 상호주의, [../LICENSE-hardware.md](../LICENSE-hardware.md)) · 문서 **CC BY-SA 4.0** · 관측 **데이터 CC BY 4.0**(허용형이라 시민과학 데이터가 자유롭게 합쳐지고 인용된다). [../LICENSE-docs.md](../LICENSE-docs.md).

---

## 1. 설계와 함께 이동하는 네 가지 규칙

Precious Plastic은 안전을 무시해서 퍼진 것이 아니다. 공개 설계에 소수의 타협 불가한 규칙(환기하라, 절대 태우지 마라)을 짝지어 두고 나머지는 전부 현지 운영자에게 넘겼기 때문에 퍼졌다. 아래는 우리의 것이다. 규제가 아니라 가치이며, 이것이 오픈소스 확산을 무모함이 아니라 신뢰로 만든다.

1. **회수한다.** 이것은 해양쓰레기 프로젝트다. 물에 남겨진 기기는 우리가 싸우는 바로 그 문제다. 모든 기기를 회수 가능하게 설계하고(고가시성, 연락처 라벨, 회수 고리), 추적하고, 가서 건진다. 회수할 수 없다면 방류하지 않는다. 회수는 부과된 규칙이 아니라 우리의 정체성이다.
2. **안전 전원, 무독성.** 보호회로가 있는 Li-ion 셀을 쓴다. 0도 미만에서 충전하거나 하우징이 45도 넘게 달아오르게 두지 않는다. 단일 셀 고장을 함체 안에 가둔다. 태우지 않고, 유해물질을 쓰지 않으며, 비금속 RF 투과 하우징을 쓴다. 기기 자체의 발자국을 고려한다.
3. **물과 물의 이용자에게 해를 끼치지 않는다.** 야생동물을 얽거나 그물과 프로펠러에 걸리지 않는 매끈한 형상. 현지 허가가 없으면 보호구역이나 민감 구역, 번식기를 피한다. 주변 물 이용자에게 알린다.
4. **네 배포는 네가 책임지고, 지역 규정을 따른다.** 공유 수역에 방류하고 셀룰러나 무선으로 송신하는 것은 나라마다 다르게 규제된다. 우리는 설계를 주고, 배포는 당신 것이다. 작게 시작하고(몇 기), 배우고, 확대한다. 5장에 제네릭 localize 체크리스트가 있고 한국을 예시로 넣었다.

미성년 참여 배포는 추가의 필수 규칙이 있다 — [../SAFETY_MINORS.md](../SAFETY_MINORS.md).

---

## 2. 동작 방식

타이머로 깨어나 GPS fix를 얻고, 작은 JSON ping 하나를 셀룰러망으로 POST하고, 잔다. 기기는 좌표 한 점만 보내고 서버가 궤적을 조립한다. 사용자가 세울 게이트웨이나 인프라는 필요 없다. 이동통신망이 곧 인프라다.

```
[드리프터] --GPS fix--> --셀룰러 POST--> [수신 서버] --> [공개 지도 / 오픈 데이터]
    잔다 <------------------------------------ 200 OK
```

ping·궤적 형식은 **FF-ID v1.1**이며 **[../data/schema.md](../data/schema.md)**에 한 번만 정의된다(`obs_id`·provenance·QC·물리 공변량 포함). JSON을 여기 손으로 복사하지 않는다 — 복제된 스키마는 서로 어긋나고, 그것이야말로 표준이 막으려는 상호운용 실패다. 자체 수신 서버([../server/README.md](../server/README.md))를 돌리거나 공유 커뮤니티 엔드포인트로 POST한다. 데이터는 **CC BY**로 커뮤니티에 속한다.

---

## 3. 티어 선택 (개념)

던지려는 질문에 답하는 가장 낮은 티어를 고른다. 부유체 몇 개로 하는 하천 조사에는 견고 티어가 필요 없다. 싸게 시작해 파이프라인을 증명하고 확대한다.

- **Tier 0 — 폰 인 어 보틀**(~USD 5–35): 재사용 스마트폰 + GPS 로깅 앱을 밀봉 병에. 전체 사슬(기기→서버→지도)을 거의 무료로, 어디서나, e-waste로 증명한다. 먼저 이걸 쓴다.
- **Tier 1 — 셀룰러 보틀**(~USD 50–70, **운동의 기본**): 폐페트병 안에 ESP32 셀룰러 보드. 가장 확산성이 높고, 무인 운용이 가능한 최저가이며, 그 자체가 연구 대상인 쓰레기다.
- **Tier 1.5 — 태양광 보조 장기체류**(Tier 1 + 감싸는 박막 셀): 회수까지 수 주가 걸릴 수 있는 장기 모니터링용 — [../hardware/TIER1_5_SOLAR_DRIFTER.md](../hardware/TIER1_5_SOLAR_DRIFTER.md).
- **Tier 2 — 재사용 견고**(~USD 90–130): 볼트 밀봉 IP 등급 함체, 외부 안테나, 온도보상 충전, 자기복원 킬. 반복·냉수·가혹 캠페인용이지 출발점이 아니다.

**모든 티어의 부품표는 기능별 현지 대체와 함께 [../hardware/BOM.md](../hardware/BOM.md)에 있다.** 그 표 하나만 최신으로 유지하며, 이 문서는 의도적으로 복사하지 않는다.

모든 셀룰러 티어 공통 주의(펌웨어·CAD에 강제됨):
- 레퍼런스 보드의 GNSS는 **별도 L76K 칩**이며 전용 UART로 읽는다(NMEA를 TinyGPSPlus로). 모뎀 AT GNSS가 아니다. 이 분리가 핵심이다 — 모뎀이 자는 동안 GPS가 돌기 때문에 store-and-forward 배터리 수명이 나온다. 펌웨어 라이브러리는 **lewisxhe/TinyGSM-fork**여야 한다(스톡 TinyGSM엔 A7670 매크로 없음).
- **항상 배터리를 장착하고 테스트한다.** USB만 급전하면 송신 피크에서 브라운아웃이 나 모뎀 불량처럼 보인다.
- **하우징은 비금속, 안테나는 수면 위.** 아니면 GPS와 셀룰러가 둘 다 죽는다. (태양광 변형은 하드 게이트를 더한다 — RF 창을 덮는 금속 기판 셀은 CAD에서 거부된다. FLOAT_STANDARD 참조.)

---

## 4. 통신: 지역에 맞는 백홀 선택

셀룰러는 가장 단순한 글로벌 선택지다. 이동통신망은 이미 사람이 있는 곳 어디에나 있기 때문이다. 지역에 따라 다른 두 가지는 LTE 밴드와 SIM이다.

지역별 셀룰러 보드 변형(A7670 계열, 밴드에 맞게 선택):

| 변형 | 대표 LTE-FDD 밴드 | 적합 |
|---|---|---|
| A7670E | B1/B3/B5/B7/B8/B20 | 유럽, 중동, 아프리카, 한국, 아시아 대부분, 호주 |
| **A7670G** | 글로벌 멀티밴드(미주 밴드 추가, 예: B2/B4/B12/B25/B66) | 미주 및 전 세계 로밍 — **레퍼런스 보드** |
| A7670SA | 라틴아메리카 밴드 | 중남미 |

레퍼런스 빌드는 밴드 커버리지를 최대화하려 **T-A7670G R2**(글로벌 변형)를 쓴다. 변형을 통신사 밴드에 맞추되, 밴드 목록을 확인하지 않고 특정 변형이 지역 잠금이라고 가정하지 않는다. SIM7080G(LTE-M / NB-IoT)로 **대체하지 않는다** — 한국 상용망에서 검증된 attach가 없다.

SIM 선택지, 쉬운 순:
- **글로벌 IoT SIM**(1NCE, Soracom): SIM 하나가 여러 나라에서 작동한다. 로밍이라 현지 기기 등록을 우회하므로 자작 기기에 이상적이다. 당신 나라에서 어느 현지 통신사로 로밍되는지 확인한다(예: 한국에서는 KT/SKT로 로밍, LG U+는 아님). Soracom은 제휴 통신사 커버리지가 있는 곳에서만 의미가 있고, 단일국 파일럿에서는 현지 선불 SIM이 대개 더 간단하고 싸다.
- **현지 선불 데이터 SIM**: 나라별 최저가. 자작(무인증) 기기가 데이터에 붙는 게 허용되는지 확인한다.

**셀룰러 커버리지가 없는 곳**(오지·농촌 하천)? 레퍼런스 펌웨어는 셀룰러 전용이며, LoRa는 *문서로 소개하는 대안 백홀일 뿐 레퍼런스 빌드의 일부가 아니다*. Meshtastic은 면허 불요 ISM 밴드(868 MHz 유럽·아프리카 · 915 MHz 미주·호주 · 923 MHz 아시아 대부분 · KR920 920–923 MHz 한국)로 동작하지만 가시선이 확보된 커뮤니티 게이트웨이 1~2대가 필요하다. 이 리포 펌웨어의 범위 밖이며, 그 경로를 택한다면 상류 Meshtastic 프로젝트 문서를 따른다.

### 원가 — 왜 통합 보드인가, 그리고 위성은 실제로 얼마인가

빌더가 늘 묻는 두 질문. 가격은 단품 수입 소매가(나라·수량·관세·배송에 따라 달라진다).

**"부품 셋을 따로 사면 통합 보드보다 싸지 않나?"** 잘해야 근소하게, 그리고 물에 들어가면 아니다:

| 방식 | 부품 | ~USD |
|---|---|---|
| 따로 | ESP32 개발보드 | 1–5 |
| | A7670E LTE Cat.1 모듈(브레이크아웃) | 14–17 |
| | GNSS 모듈(NEO-6M / ATGM336H급) | 3–5 |
| | **소계** | **~21–26** |
| 통합 | LILYGO T-A7670G R2 (GNSS 포함) | **~27** (제조사 스토어) |

값의 바닥은 ESP32(~$4)가 아니라 **LTE 모뎀(~$15)**이다 — 모뎀은 어느 쪽이든 사야 하므로 통합을 피해도 아끼는 게 적다. 따로의 ~$3–5 종이상 절감은 이런 것들에 먹힌다: 납땜점·커넥터 3배(방수 기기에선 하나하나가 누수·고장점), 안테나 2–3개 별도 소싱, 내장 SIM 슬롯·전원경로·UART 레벨시프팅·USB 프로그래밍 없음, 부피·질량 증가(병과 자기복원에 불리), 레퍼런스 보드 기준으로 짜인 펌웨어 핀맵. 통합이 **신뢰 단위당** 더 싸다. 진짜 절감은 자체 PCB로 수백 대를 뜰 때만 나오며 — 그때는 통합 보드를 스스로 다시 만든 셈이다. (한국: 더 싼 LTE-M/NB-IoT 부품으로 모뎀 값을 우회할 수 없다 — SIM7080G는 국내망 접속이 검증되지 않았다.) 대개 **제조사 자체 스토어**(예: 메이커 공식 AliExpress 스토어, 선전 공장 직판)가 최저가이고, 리셀러는 마진과 현지 창고 편의를 얹는다.

**"위성(Class 3 — 셀룰러 밖 외해)은 얼마나 비싼가?"** 대략 하드웨어 10배 + 지속 통신료:

| 위성 경로 | 하드웨어 | 통신료 | 비고 |
|---|---|---|---|
| Myriota / Astrocast | 모듈 ~$20–40 | 저가 구독 | **store-and-forward, 실시간 아님**(위성 지나갈 때 전송, 수 분~수 시간 지연). 저빈도 계측엔 무방, 실시간 추적엔 부적합 |
| Swarm M138 | ~$150 | ~$60/년 | 싼 양방향이었으나 **2023 신규판매 중단**(SpaceX) — 신규 빌드엔 경로 아님 |
| **Iridium RockBLOCK 9603** | **~$250–270** | 회선 **~$15/월** + 메시지당 크레딧(50바이트=1크레딧) | **진짜 전지구·외해 포함·실시간** SBD — 해양 드리프터 표준 |

~$27 셀룰러 유닛과 견주면, 실시간 외해 추적(Iridium)은 **하드웨어 ~10배 + 매달 청구**다. 레퍼런스 설계가 셀룰러 커버리지 안의 강→연안을 겨냥하고 위성을 Class 3으로 분리한 이유가 바로 이것 — 기지국이 육지에 있어 외해로 나가면 셀룰러가 침묵하며, 이는 더 싼 보드로 못 풀고 오직 위성으로만 풀리는데 그 값이 위와 같다.

### 소싱 — 무엇을 수입하고 무엇을 국내에서 사나

사양이 걸린 부품은 단 둘이다. 나머지는 이미 로컬에 있는 범용 부품이다.

- **셀룰러 보드.** 국내 유통사를 먼저 확인한다 — 빠르고, 통관 없고, 국내 보증되고, 판매자가 이미 적합성평가(전파인증)를 마쳤다. 국내에 없으면 제조사 자체 공식 스토어(예: 공장 직판 AliExpress 스토어)가 대개 최저가다. 특송(DHL/FedEx)은 빠르지만 단품 주문에선 배송비가 보드값과 맞먹을 수 있고, 면세한도 이하여도 통관수수료를 붙이기도 한다 — 표준/우체국은 느려도 착지가가 대개 더 싸다. 자작 셀룰러 기기는 어딘가에서 규제 대상이다([DEPLOY_responsibly.md](DEPLOY_responsibly.md) 참조). 국내 재고 보드를 사면 개인수입 승인 문제를 우회한다.
- **태양 필름(Tier 1.5 한정) — 값싼 로컬 패널이 설계를 조용히 깨뜨리는 유일한 부품.** "플렉시블 박막"은 *형태*이지 재료가 아니며, RF와 독성을 가르는 건 재료다:
  - **a-Si(비정질 실리콘), ETFE/플라스틱 전면 — 권장.** 비금속 → RF 투과(B5)·비독성·저가(소형 5–6 V ~$5–20). 드리프터의 저전력 예산은 고효율이 불필요하므로, 여기선 드물게 **제일 싼 것이 곧 맞는 선택**이다.
  - **CIGS** — 효율은 높지만 흔한 플렉시블 CIGS는 **스테인리스 기판**(CIGS가 500°C+ 공정이라 업계 표준)이라 안테나 위 금속 RF 차폐 = 실격. **폴리이미드**(비금속) 위 Cd-free CIGS만 허용되며, 덜 흔하고 더 비싸다. 여기서 CIGS에 더 쓰지 마라.
  - **CdTe / 페로브스카이트 — 불가**(독성/미성숙/RF).
  - 출처 불문 규칙: **기판이 비금속인지 확인하라.** 스테인리스 기판이면 나머지가 완벽해도 통신이 죽는다.
- **나머지는 전부 로컬:** 보호회로 18650, SIM, uFL 안테나, 페트병, 밸러스트(낚시 봉돌), 방수 실런트, 고시인성 테이프 / QR 라벨 / 회수 고리, 인쇄 인서트(직접 출력). 수입할 게 없다.

---

## 5. 책임 있는 배포 — localize (제네릭, 하나의 예시와 함께)

우리는 설계를 준다. 방류는 당신 것이다. 물에 기기를 넣기 전에 이 제네릭 체크리스트를 걷고 당신 나라의 규정을 적용한다. 이것이 오픈소스 프로젝트가 무모함 없이 퍼지게 하는 "단서를 다는" 단계다. 벽이 아니라 습관이다. 하드 게이트를 포함한 완전판은 **[DEPLOY_responsibly.md](DEPLOY_responsibly.md)**와 **[DIY_DIVERSITY.md](DIY_DIVERSITY.md) §4.4**에 있다.

제네릭 체크리스트(어디서나 적용):
- **전파/통신.** 자작 셀룰러나 무선 송신기는 어딘가에서 규제된다. 소규모 연구/DIY 송신기에 형식승인, 면제, 허가가 필요한지, 당신 SIM/밴드가 허용되는지 확인한다. 글로벌 IoT 로밍 SIM이 대개 이를 단순화한다.
- **수역 접근.** 당신이 방류하는 물은 누군가 관리한다(시 하천, 국가하천, 보호 습지, 항만, 연안). 누구인지 알아내 물어본다. 보호·유산·습지 구역은 대개 추가 동의가 필요하므로, 첫 파일럿은 평범한 지역 하천을 선호한다.
- **배터리와 e-waste.** 물속 Li-ion은 유실 시 발화·오염 위험이다. 보호하고, 가두고, 무엇보다 회수한다(규칙 1). 셀 수명 종료 계획을 둔다.
- **야생동물과 다른 이용자.** 매끈하고 얽히지 않는 형상. 번식기와 보호종 구역을 피한다. 어민, 항만청, 해경에 알려 미상의 밀봉 전자상자가 해안에 밀려와 경보가 되지 않게 한다.
- **작고 정직하게 시작.** 몇 기, 전량 회수, 회수율과 표류 거동을 배우고, 더 큰 방류를 어림수가 아니라 측정값에서 산정한다.

예시 — 한국(여러 지역 중 하나):
- **전파:** 야외 다수용 자작 셀룰러 기기는 적합성평가 대상이다. 방류 전 국립전파연구원(RRA)에서 연구·기술개발용 면제확인(별지 제12호, 1,500대 이하)을 받는다. 글로벌 IoT 로밍 SIM(KT/SKT)이 현지 기기 등록을 우회한다.
- **수역:** 낙동강 본류·하구는 국가하천에 더해 천연기념물·습지 보호구역이다(국가 수준 동의). 평범한 지류 하천(시·구 관리)이 저마찰 파일럿 대상지이며, 지류가 하구로 흐르므로 여전히 진짜 "source to sea"다.
- 나머지(배터리 안전, 회수 우선, 야생동물, 물 이용자 통보)는 위 보편 세트와 같다.

다른 나라: 지역별 두 줄(전파 당국, 수역 관리자)만 당신 것으로 바꾸고 나머지는 그대로 둔다. 두 번째 예시(고온·몬순·강자외선)는 [DEPLOY_tropical.md](DEPLOY_tropical.md)(베트남 다낭)에 있다. 하나 만들면 당신 지역 메모를 [DIY_DIVERSITY.md](DIY_DIVERSITY.md)에 되돌려 기여해, 당신 나라의 다음 사람이 더 빨리 시작하게 한다. 그렇게 운동이 복리로 쌓인다.

---

## 6. 합류, 기여, 데이터 공유

- 기기를 만들고, 당신 하천에 방류·회수하고, FF-ID 궤적을 자체 수신 서버나 공유 지도로 POST한다.
- 이슈 템플릿(`.github/ISSUE_TEMPLATE/`)으로 당신의 변형과 하천을 등록하고, [DIY_DIVERSITY.md](DIY_DIVERSITY.md)에 지역 메모를 추가한다.
- 설계를 개선한다: 더 나은 자기복원 병 기하, 더 싼 지역 부품 대체, 번역. 풀 리퀘스트를 연다 — CI가 CAD를 파싱하고 스키마·링크를 검사해 당신의 변경이 상호운용성을 유지하게 한다.
- 데이터는 **CC BY**. 출처 표기: *SEA:CUT / Friendly Floaty — 사단법인 이타서울 / GAA(Global Adopt-a-Beach Alliance) 및 기여자.* [../CITATION.cff](../CITATION.cff).

사단법인 이타서울 / GAA와 기여자들이 만들었다. Precious Plastic과 OpenMetBuoy를 비롯한 오픈 하드웨어 운동에서 영감받았다. 이것은 **레퍼런스 설계**다 — 현장 검증과 DOI 등록 데이터셋은 준비 중이며, 모든 수치는 벤치·현장 실측 전까지 추정치다.

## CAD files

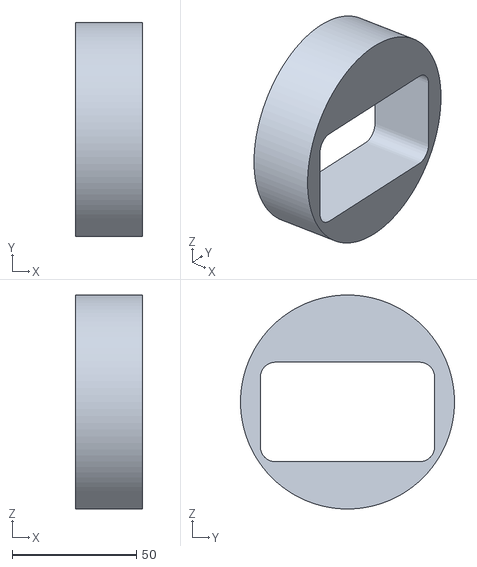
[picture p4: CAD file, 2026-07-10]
hardware/cad/asm_foam_a.stl
27.0 x 86.0 x 86.0

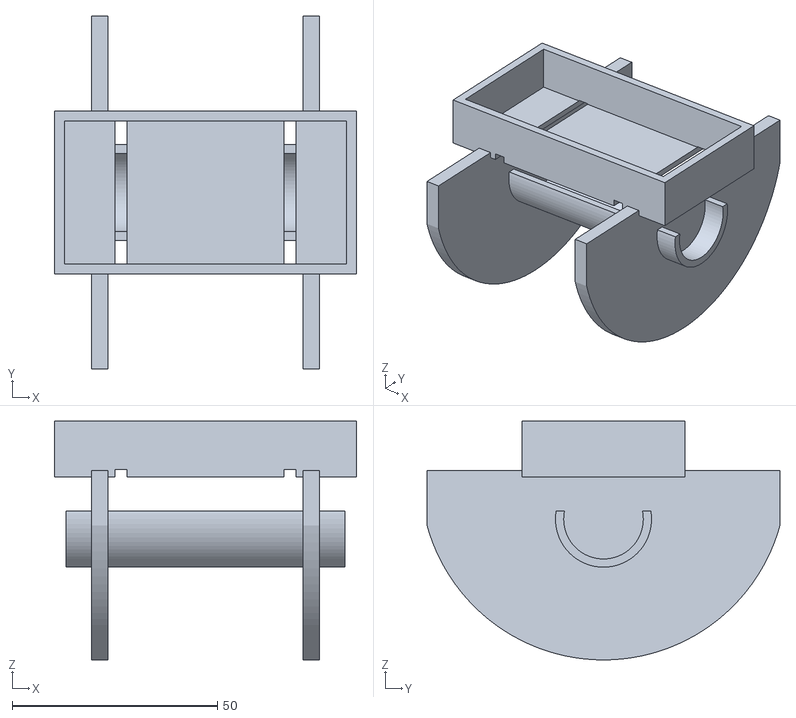
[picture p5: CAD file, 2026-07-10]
hardware/cad/asm_bracket.stl
73.6 x 86.0 x 58.2

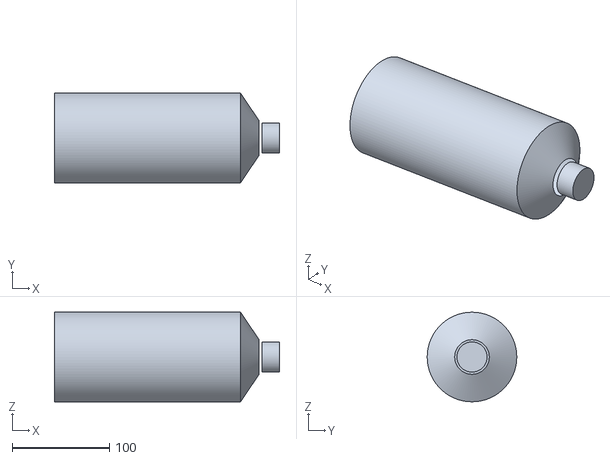
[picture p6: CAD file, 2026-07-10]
hardware/cad/asm_bottle.stl
231.0 x 92.0 x 92.0

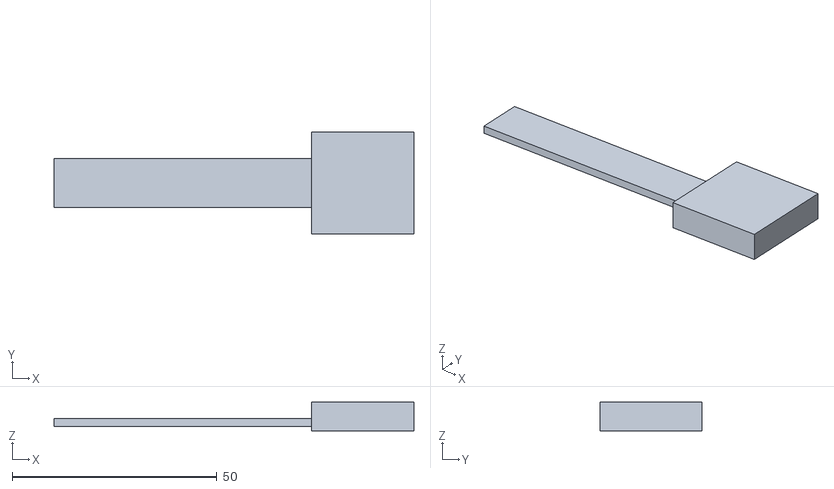
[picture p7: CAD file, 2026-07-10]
hardware/cad/asm_antennas.stl
88.0 x 25.0 x 7.00

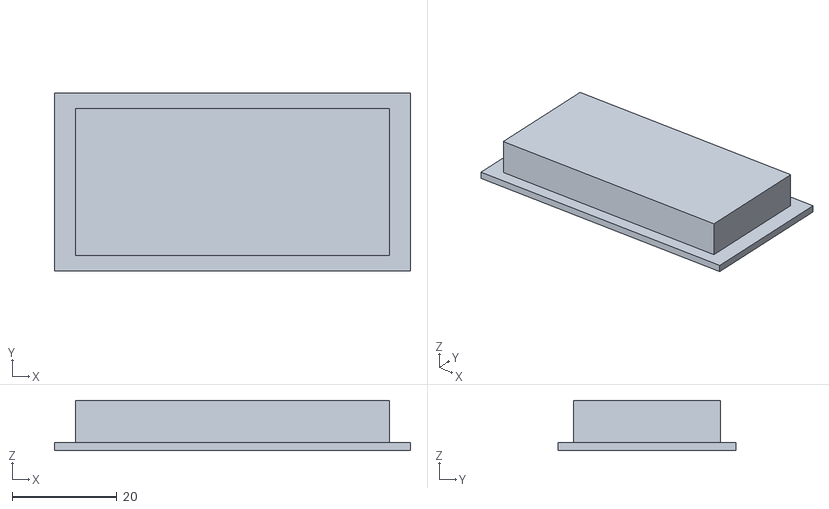
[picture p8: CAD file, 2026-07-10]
hardware/cad/asm_board.stl
68.0 x 34.0 x 9.60

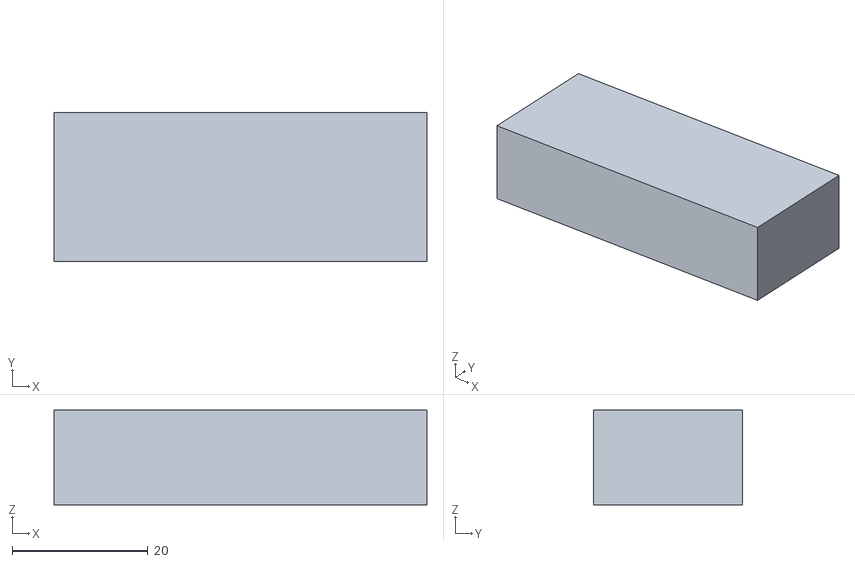
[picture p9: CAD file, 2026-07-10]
hardware/cad/asm_ballast.stl
55.0 x 22.0 x 14.0

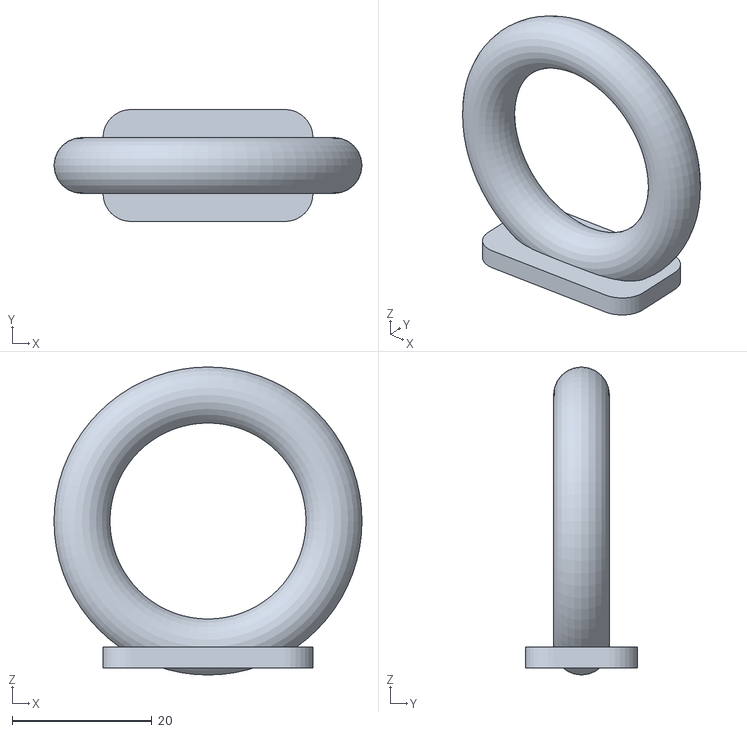
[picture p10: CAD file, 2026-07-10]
hardware/cad/asm_loop.stl
44.0 x 16.0 x 44.0

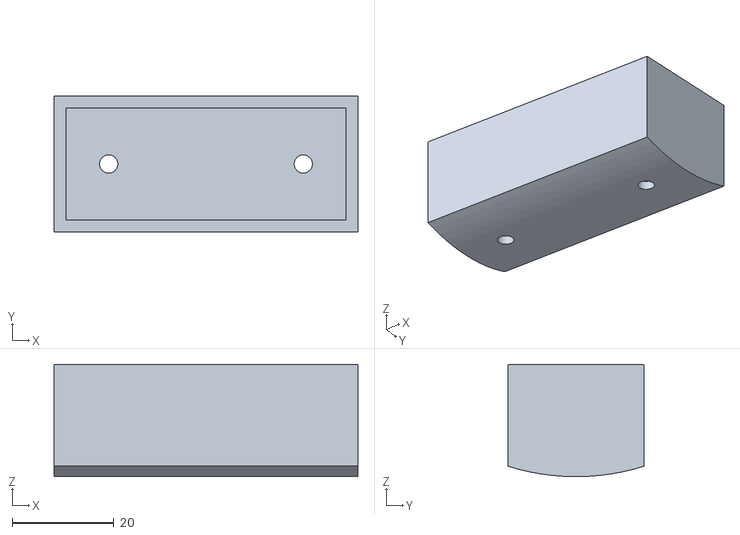
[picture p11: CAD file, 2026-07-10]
hardware/cad/asm_keel.stl
59.8 x 26.8 x 22.1

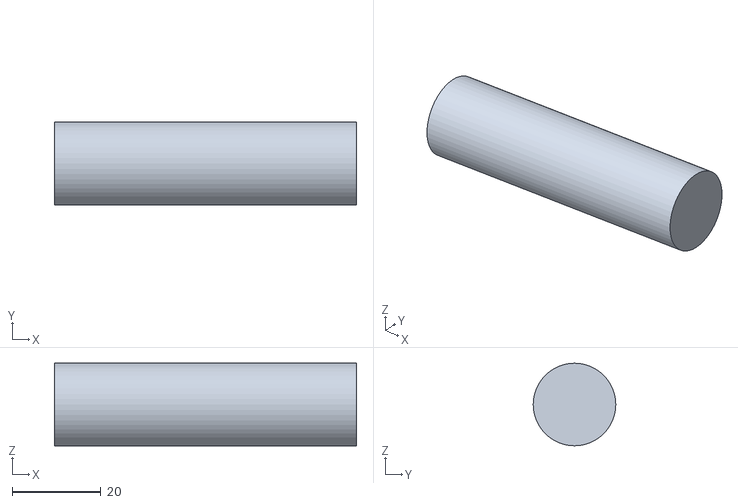
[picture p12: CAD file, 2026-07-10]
hardware/cad/asm_cell.stl
68.0 x 18.6 x 18.6

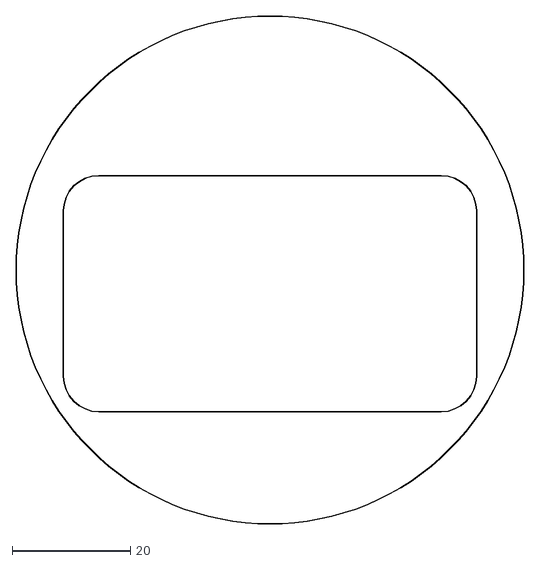
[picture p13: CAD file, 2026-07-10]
hardware/cad/foam_collar_template.dxf
86.0 x 86.0

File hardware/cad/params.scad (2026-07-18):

// SEA:CUT / Friendly Floatee drifter — shared parameters (mm)
// Hardware: CERN-OHL-S v2 (strongly reciprocal). Docs: CC BY-SA 4.0. Firmware: MIT.
// MEASURE YOUR OWN BOTTLE and edit these. Defaults approximate a 1 L round PET bottle.

// --- bottle (upcycled PET) ---
bottle_id = 90;            // bottle inner diameter
bottle_r  = bottle_id / 2; // derived inner radius

// --- printing ---
wall = 2.4;                // printed wall thickness
clr  = 0.4;                // fit clearance
$fn  = 64;                 // curve smoothness

// --- LILYGO T-A7670G board (approximate, incl. headers) ---
board_l = 68;
board_w = 34;
board_h = 12;

// --- 18650 protected cell ---
cell_d = 18.6;
cell_l = 68;

// --- lead-free ballast pocket (self-righting weight) ---
ballast_l = 55;
ballast_w = 22;

// --- flotation & hydrostatics (NEW; estimates — verify per build; see hardware/RELIABILITY.md) ---
// Sealed 1 L bottle displaces ~1000 cm^3 -> reserve ratio ~4.83x (never sinks intact).
// Real failure = seal leak -> flooded net buoyancy ~ -97 gf -> sinks. Foam reverses it.
foam_vol             = 160;   // cm^3 closed-cell foam (flooded reserve; non-BOM NEW part)
foam_density         = 0.04;  // g/cm^3 EVA/EPE estimate (range 0.03-0.05)
reserve_ratio_target = 1.25;  // flooded: (disp/mass) >= this  (PASS >= 1.20)
sealed_reserve_min   = 3.0;   // sealed: 1000cm3/mass >= this (design ~4.83)
freeboard_min        = 30;    // mm minimum calm-water freeboard
ballast_mass_g       = 40;    // tuning var; +10 g ballast needs +~11.8 cm^3 foam (1-R*rho_foam; solar=6.7)
// foam collar geometry (NEW part, cut/heat-formed EVA sheet — .scad is the cut master)
foam_od     = 86;             // mm, fits inside bottle_id=90 with margin
foam_bore_l = board_l + 2;    // ~70 mm payload channel (board_l=68)
foam_bore_w = board_w + 6;    // ~40 mm (board_w=34)
foam_area   = PI*pow(foam_od/2,2)/100 - (foam_bore_l*foam_bore_w)/100; // ~30.1 cm^2
foam_collar_h = foam_vol / foam_area;   // ~53 mm; split into 2 x ~27 mm
// prints: measured STL solid volume = 56.9 cm^3 (bracket 40.4 + keel 9.95 + loop 6.57)
print_infill_max = 0.60;  // keep <=60% -> foam_vol 160 holds; solid(100%) needs ~175

// --- full assembly (real size; visual mocks measure YOUR parts) ---
collar_t   = 27;          // foam collar thickness (2 pieces = foam_collar_h ~53)
collar_x   = 44.5;        // collar center offset +-X (clears keel ends at +-29.9)
bottle_body_l = 190;      // straight body length of a ~1 L bottle (mock)
bottle_body_x0 = -100;    // body from x0 to x0+bottle_body_l; neck/cap at +X
shoulder_l = 22;          // taper body -> neck
neck_l     = 18;          // neck + cap
cap_d      = 31;          // cap outer diameter

// ============================================================
//  Tier 1.5 SOLAR VARIANT — parameters (NEW; every value an ESTIMATE -> bench-verify)
//  Anchors: buoyancy=RELIABILITY §4 (density-aware) · RF=FLOAT_STANDARD B5
//           self-right "T7" = VERIFIED_BUILD_TEST T4 re-run with the solar payload installed
//  Kernels enforced here: NO new printed part · ballast 40 g UNCHANGED ·
//                         non-metal cells only · solar = power != coverage
// ------------------------------------------------------------
solar_enable = 0;          // 0 = plain Tier 1 (default). Solar build: set 1 or render -D solar_enable=1.
                           // ★SHORT-RECOVERY MISSIONS keep 0 (ELECTRONICS_POWER §3: solar = net loss).

bl_ref = board_l + 2*wall + 2*clr;                 // 73.6 (bracket len; ribs at +-bl_ref*0.35 = +-25.76)

// --- added-mass budget (★MEASURE; lens estimates diverge 20-45 g) ---
solar_added_mass_g = 39;   // PLANNING nominal (film 10-25 + ctrl 5-8 + wire 3-4 + vent ~2 + adhesive 3-8)
solar_add_rho      = 1.64; // g/cm^3 EFFECTIVE (film~1.65 · PCB~1.9 · wire~1.5 · adhesive~1.0)
solar_second_cell  = 0;    // 1 => +~56 g (48 cell + 8 mount), BELLY only, matched cells + isolation diode (F2/T7 re-pass)
solar_added_mass_eff = solar_added_mass_g + (solar_second_cell ? 56 : 0);  // effective Δm fed to foam sizing

// --- density-aware foam re-size (★NOT the ballast 11.7 cm^3/10g; panel is low-density) ---
solar_foam_coeff = (1.25 - 1/solar_add_rho)/(1 - 1.25*foam_density)*10;  // ~6.7 cm^3 / 10 g
foam_vol_solar   = foam_vol + solar_foam_coeff*(solar_added_mass_eff/10);  // ~186 cm^3 @ 39 g (2nd cell => ~224)
collar_t_solar   = foam_vol_solar/foam_area*10/2;                        // ~31 mm each (2 collars); assembly/export use this

// --- wrap bands (★NOT printed: laminated film + marine adhesive on the body) ---
solar_wrap_od = bottle_id + 2;   // body OD (MEASURE yours)
solar_wrap_r  = solar_wrap_od/2;
solar_film_t  = 0.8;             // laminated film thickness (fit/collision + RF-window viz ONLY)
solar_band_n  = 2;
solar_band_w  = 44;              // axial band width
solar_band_gap= 34;              // central channel >= recovery-loop base 30 (loop + QR stay bare)
solar_band_x  = [ for (i=[0:solar_band_n-1])
                  (solar_band_n==1) ? 0 : (i-(solar_band_n-1)/2)*(solar_band_w+solar_band_gap) ]; // +-39

// --- RF keep-out (★REAL gate = non-metal substrate; the film window is secondary insurance) ---
solar_cell_substrate = "nonmetal"; // HARD GATE: a-Si / polyimide ONLY. "metal" => ABORT (B5; verify T6)
solar_rf_x0 = -50; solar_rf_x1 = 48;  // antenna x-range (doc only; the window currently cuts the full band length)
solar_rf_deg = 120;                   // top +Z sector kept FILM-FREE (cut across the whole band = conservative)

// --- charge path (★default EXTERNAL low-Iq linear -> BATTERY terminal; NOT onboard-direct) ---
solar_ctrl_mode = "linear";  // "linear"=CN3065-class low-Iq (DEFAULT) | "mppt"=CN3791-class (clean sites)
solar_ctrl_l=26; solar_ctrl_w=19; solar_ctrl_h=7;   // COTS envelope (CG viz only), zip-tied to bracket rib
solar_ctrl_x = -bl_ref*0.35;  // -25.76 : on the -X bracket locating rib
solar_ctrl_z = -2;            // just below centreline, BESIDE the cell holder (keep CG low -> T7)

// --- low-temp cutoff (★MANDATORY on ALL modes — HARDWARE latch, not firmware) ---
solar_ntc = "10k_B3435_cell_bonded";  // JEITA: <0C stop · 0-10C taper · >45C stop (epoxy to cell can)

// --- wiring: REUSE the resealed-seam grommet (assembly §3-0) — NO NEW HOLE; re-pass T1 ---
solar_wire_od = 3.0;
// --- vent: Gore-Tex ePTFE ADHESIVE PATCH on the cap (NOT a printed boss) ---
solar_vent_patch_d = 19;

// ★HARD GATE (FLOAT_STANDARD B5) — makes the "metal => ABORT" claim TRUE in code, not just prose.
//   Any file that includes params.scad aborts if a metal-backed cell substrate is selected.
assert(solar_cell_substrate != "metal",
       "B5: metal-backed solar cells shield the antennas (RF death) + are toxic -> ABORT. Use a-Si (ETFE) or Cd-free CIGS (polyimide).");

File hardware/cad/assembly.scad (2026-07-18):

// Friendly Floaty — FULL real-size assembly (printed parts + foam + electronics mocks)
// Renders the complete Tier-1 drifter as deployed: horizontal 1 L bottle, keel at the
// belly, board+cell in the bracket, 2 foam collars (flooded-reserve buoyancy),
// antennas up, recovery loop on top.
//
//   assembled : openscad -o assembly.png --autocenter --viewall --imgsize=1400,1000 assembly.scad
//   exploded  : openscad -o assembly_exploded.png -D explode=1 --autocenter --viewall --imgsize=1400,1000 assembly.scad
//
// Axes: X = bottle long axis (+X = cap), +Z = up (antenna side).
include <params.scad>
use <electronics_bracket.scad>
use <ballast_keel.scad>
use <recovery_loop.scad>
use <foam_collar.scad>
use <mockups.scad>
use <solar_variant.scad>

explode = 0;          // 0 = assembled, 1 = exploded (CLI: -D explode=1)
e = explode * 60;

// printed parts
color("SteelBlue")      translate([0, 0,  e * 0.30]) electronics_bracket();
color("DimGray")        translate([0, 0, -e * 0.80]) ballast_keel();
color("Orange")         translate([0, 0, bottle_r + 1 + e * 1.40]) recovery_loop();

// foam collars (cut from EVA sheet — flooded-reserve buoyancy, RELIABILITY §4)
// ★solar build re-cuts LARGER foam (collar_t_solar ~31 mm) so the flooded reserve stays >= 1.20 at +39 g
color("Khaki")          translate([ collar_x + e * 1.2, 0, 0]) foam_collar(solar_enable ? collar_t_solar : collar_t);
color("Khaki")          translate([-collar_x - e * 1.2, 0, 0]) foam_collar(solar_enable ? collar_t_solar : collar_t);

// electronics / ballast mocks (real size)
color("ForestGreen")    translate([0, 0,  e * 0.90]) board_mock();
color("DarkSeaGreen")   translate([0, 0,  e * 1.15]) antennas_mock();
color("LightSlateGray") translate([0, 0, -e * 0.35]) cell_mock();
color("SlateGray")      translate([0, 0, -e * 1.20]) ballast_mock();

// bottle shell (translucent)
color("LightSkyBlue", 0.25) bottle_mock();

// --- Tier 1.5 SOLAR VARIANT overlay (render with -D solar_enable=1; default 0 = plain Tier 1) ---
// Wrap = adhesive film (no print) · controller = COTS on the bracket · vent = Gore-Tex patch.
// The RF window must sit over the antennas (+Z). Ballast/keel/loop/bracket are untouched (kernel #6).
if (solar_enable) {
    color("MidnightBlue", 0.60) solar_wrap();                                   // film semi-transparent so internals read
    color("Gainsboro")
        translate([bottle_body_x0 + bottle_body_l + shoulder_l + neck_l - 2, 0, 0])
        rotate([0, 90, 0]) solar_vent_patch();                                  // vent patch, cap end (+X)
    color("Crimson")
        translate([solar_ctrl_x, board_w/2 + 3 + e * 1.6, solar_ctrl_z]) solar_controller_mock();  // COTS charge controller (on bracket rib, low CG)
    color("Gold")
        translate([0, e * 1.6, 0]) solar_ntc_mock();                            // NTC bead on the cell (low-temp cutoff)
    if (explode == 0) {                                                          // wiring routing shown in the assembled view only
        color("Orange") solar_wire_panel();                                     // panel-in lead: film -> seam grommet -> controller
        color("Red")    solar_wire_batt();                                      // charge + NTC leads: controller -> 18650
    }
    solar_report();  // foam collars above already re-cut to collar_t_solar via the solar_enable branch
}

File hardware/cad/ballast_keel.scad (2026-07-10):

// SEA:CUT / Friendly Floatee — ballast keel (self-righting)
// Seats at the belly (-Z) and carries lead-free weight low, so the float always
// rights itself antenna-up no matter how it rolls.
// Axes: X = bottle long axis, -Z = belly.
include <params.scad>

module ballast_keel() {
    Lx = ballast_l + 2*wall;
    Wy = ballast_w + 2*wall;
    Hz = bottle_r * 0.5;
    difference() {
        // slab at the belly, trimmed to the bottle inner wall
        intersection() {
            translate([-Lx/2, -Wy/2, -bottle_r]) cube([Lx, Wy, Hz]);
            rotate([0, 90, 0]) cylinder(h = Lx + 4, r = bottle_r - clr, center = true, $fn = 120);
        }
        // open weight pocket (pack with lead-free sinkers, then seal)
        translate([-ballast_l/2, -ballast_w/2, -bottle_r + wall]) cube([ballast_l, ballast_w, Hz]);
        // zip-tie / drain holes
        for (x = [-Lx*0.32, Lx*0.32])
            translate([x, 0, -bottle_r - 1]) cylinder(h = Hz + 2, r = 1.8, $fn = 24);
    }
}

ballast_keel();

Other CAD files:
hardware/cad/asm_foam_b.stl
hardware/cad/recovery_loop.stl
hardware/cad/electronics_bracket.stl
hardware/cad/ballast_keel.stl
hardware/cad/electronics_bracket.scad
hardware/cad/export_part.scad
hardware/cad/foam_collar.scad
hardware/cad/foam_collar_2d.scad
hardware/cad/mockups.scad
hardware/cad/recovery_loop.scad
hardware/cad/solar_variant.scad

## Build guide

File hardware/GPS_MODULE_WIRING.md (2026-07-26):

# hardware/GPS_MODULE_WIRING.md — GPS 없는 보드에 GPS 모듈 붙이기 (대체 경로)

> **한 줄 요약**: 레퍼런스 보드(T-A7670G R2 **With GPS**)가 품절이거나 비쌀 때, **"Without GPS" 보드 + 별도 GNSS 모듈**로 같은 기능을 만든다. ★**A7670 모뎀에는 GNSS가 없다** — 그래서 "With GPS" 보드도 사실은 **Quectel L76K 칩을 ESP32 UART에 물려놓은 것**뿐이다. 즉 이 경로는 꼼수가 아니라 **레퍼런스와 같은 구조**다. 단 **전원 게이팅**을 틀리면 전력 예산이 무너진다(§3).

정본 의존: [BOM](BOM.md) · [ELECTRONICS_POWER](ELECTRONICS_POWER.md) · [RELIABILITY](RELIABILITY.md) · [SELF_RIGHTING](SELF_RIGHTING.md) · 펌웨어 [drifter_a7670_cat1](../firmware/drifter_a7670_cat1) · [firmware/README](../firmware/README.md)

★**이 경로는 이 리포에서 아직 벤치 검증되지 않았다**(레퍼런스는 온보드 L76K 변형). 아래는 설계 지침이며, §6 검증을 통과해야 `verified_build`로 인정한다.

---

## 0. 왜 이 문서가 있나 — 판매 옵션 이름의 혼란

LILYGO 판매 페이지의 색상 옵션 `Built-in GPS` / `External GPS` / `Without GPS`는 **무엇이 상자에 들어오는지가 불명확**하다. 실제로 LILYGO 공식 코드 예제는 **온보드 L76K를 다루면서도 이름이 `ExternalGPS_A7670G_Only`**다(모뎀 기준 '외장'이라는 뜻). 따라서:

| 옵션 | 우리 해석 | 대응 |
|---|---|---|
| **Built-in GPS** | L76K가 보드에 납땜됨 | ★**1순위**(레퍼런스). 그대로 쓴다 |
| **External GPS** | ★**불명확** — 커넥터만인지, 모듈이 동봉인지 판매자마다 다를 수 있음 | **구매 전 판매자에게 "L76K 모듈이 상자에 들어오나" 확인.** 확인 안 되면 사지 말 것 |
| **Without GPS** | GPS 전무 | 이 문서의 경로(별도 모듈 배선) |

★**모호함을 피하는 확실한 길**: `Without GPS`를 사고 GNSS 모듈을 **우리가 직접 물린다**. 그러면 상자에 뭐가 오든 상관없다.

---

## 1. 모듈 선택

| 항목 | 요구 | 비고 |
|---|---|---|
| 인터페이스 | **UART(NMEA 출력)**, 기본 **9600 bps** | L76K·NEO-6M·ATGM336H 모두 해당 |
| 로직 전압 | **3.3 V** | ESP32는 3.3V. 5V 로직 모듈 금지(레벨 시프터 필요) |
| 전원 | **3.3 V 입력**(모듈 자체 레귤레이터 있으면 3.3~5V 허용) | ★§3의 게이팅 레일에서 급전 |
| 안테나 | 세라믹 패치(내장) 또는 액티브 안테나 | ★§4 배치 주의 |
| 소비 | 추적 시 25~45 mA급 | 게이팅 필수 사유 |

권장: **L76K 모듈**(레퍼런스와 동일 칩 = 변수 최소) → 없으면 **ATGM336H** 또는 **NEO-6M**(둘 다 9600·3.3V·NMEA 표준).

---

## 2. 배선 (T-A7670G R2 기준, 우리 펌웨어 핀맵 그대로)

펌웨어 `drifter_a7670_cat1.ino`가 이미 이 핀으로 정의돼 있어 **핀을 그대로 쓰면 코드 수정이 없다.**

| GPS 모듈 핀 | → ESP32 / 보드 | 펌웨어 상수 | 설명 |
|---|---|---|---|
| **TX** (모듈이 내보냄) | **GPIO 22** | `BOARD_GPS_RX_PIN 22` | ESP32가 NMEA를 **받는** 선 ★가장 중요 |
| **RX** (모듈이 받음) | **GPIO 21** | `BOARD_GPS_TX_PIN 21` | 설정 명령용(안 써도 연결 권장) |
| **VCC** | ★**게이팅되는 3.3 V 레일(V3V)** | `BOARD_POWERON 12`이 제어 | §3 필독 |
| **GND** | GND | — | 공통 접지 |
| (선택) WAKEUP/EN | GPIO 19 | `BOARD_GPS_WAKEUP_PIN 19` | 모듈에 있으면 연결(없으면 미사용) |

- 통신 속도 **9600 bps**(`GPS_BAUDRATE 9600`), 포트 **Serial2**(`SerialGPS`).
- ★**TX↔RX는 교차**한다(모듈 TX → ESP32 RX). 이 한 줄을 뒤집으면 NMEA가 0바이트로 나온다.
- 다른 핀을 쓸 수밖에 없으면 `.ino`의 `BOARD_GPS_RX_PIN` / `BOARD_GPS_TX_PIN`만 고친다.

```
   [GNSS 모듈]                 [T-A7670G R2 / ESP32]
      TX  ──────────────────▶  GPIO 22   (NMEA 수신)
      RX  ◀──────────────────  GPIO 21
     VCC  ◀───── V3V (GPIO 12 = BOARD_POWERON 으로 켜고 꺼지는 레일)
     GND  ─────────────────── GND
  (EN/WAKE) ◀──────────────── GPIO 19  (모듈에 있을 때만)
```

---

## 3. ★★전원 게이팅 — 여기를 틀리면 프로젝트가 무너진다

GNSS 모듈은 켜져 있는 동안 **25~45 mA**를 먹는다. 딥슬립 중에도 계속 켜져 있으면:

| 급전 방식 | 슬립 소비 | 60분 핑 배터리 수명 |
|---|---|---|
| **게이팅 레일(V3V)** ✅ | 기존과 동일(2~12 mA) | **~6~19일**(정상, ELECTRONICS_POWER §1.5) |
| 상시 3.3V 직결 ❌ | +30 mA 이상 | **~2~3일로 붕괴** |

- **정답**: 보드의 **V3V 레일**에서 딴다. 이 레일은 **GPIO 12(`BOARD_POWERON`)로 켜고 꺼지며**, 온보드 L76K도 원래 여기서 전원을 받는다(펌웨어 README, hole A2). 즉 **레퍼런스와 같은 게이팅을 그대로 물려받는다.**
- V3V 접근점: TF카드 VDD 패드 또는 PX 헤더 16번 핀(펌웨어 README의 프로브 지점과 동일). **확인법**: GPIO12 LOW에서 0 V, HIGH에서 3.3 V가 나와야 한다.
- ★**USB를 꽂은 채로는 검증되지 않는다** — USB VBUS가 V3V를 살려두어 게이팅이 가려진다. **반드시 배터리만으로** 측정.
- V3V 용량이 부족하면(모듈이 커서 전압 강하) 별도 **로드스위치(P-ch MOSFET)**를 GPIO로 제어해 급전한다. 상시 급전은 어떤 경우에도 금지.

---

## 4. 기구 배치 (부력·자기복원·RF에 영향)

1. **★안테나는 위(하늘)로.** 세라믹 패치 안테나는 하늘을 봐야 한다. 이 유닛은 **수평 자세로 고정**되어 뜨므로(SELF_RIGHTING), 모듈을 **패치면이 위를 향하게** 고정한다. 옆·아래로 향하면 위성이 안 잡힌다.
2. **★솔라 필름의 '필름-프리 창' 아래에 둔다.** Tier 1.5는 몸통을 필름으로 감되 **위쪽 120° 섹터를 비워** 안테나 경로를 확보한다([TIER1_5](TIER1_5_SOLAR_DRIFTER.md) §1). GPS 패치가 필름 아래로 들어가면 수신이 나빠진다.
3. **질량·CG 재계산**: 모듈+안테나+배선이 대략 **+10~20 g** 늘어난다 → `cad/self_righting.py`의 부품 목록에 추가해 **GM > 0**을 재확인하고, 폼도 [RELIABILITY](RELIABILITY.md)·[TIER1_5](TIER1_5_SOLAR_DRIFTER.md) §5 계수로 재산정한다. **밸러스트 40 g은 불변**(상쇄로 줄이지 말 것).
4. **배선 고정**: 진동·표류로 선이 흔들리면 납땜부가 끊긴다. 케이블타이·에폭시로 스트레인 릴리프.

---

## 5. 펌웨어 (수정 최소)

- 핀을 §2대로 쓰면 **코드 수정 없음**.
- ★**데이터 정직성**: 스키마의 `gnss_source` 필드가 현재 `"l76k"`로 하드코딩돼 있다([schema](../data/schema.md)). **다른 모듈을 쓰면 실제 모델명으로 바꾼다**(예: `"neo6m"`, `"atgm336h"`). 안 바꾸면 데이터가 출처를 거짓말한다.
- 첫 확인은 **원시 NMEA가 들어오는지**부터: 시리얼에 `NMEA chars=`가 0보다 커야 한다(0이면 §2의 TX/RX 교차 또는 §3의 전원부터 의심).

---

## 6. 검증 (이 경로 전용 추가 항목)

기존 게이트(T1·F2·T4/T7·T6·G5·G6·G7)에 **아래를 더 통과**해야 이 빌드를 쓴다.

| # | 항목 | 합격 기준 |
|---|---|---|
| X1 | **NMEA 수신** | 시리얼에 NMEA 문자 유입 > 0, 문장 파싱 성공 |
| X2 | **야외 콜드 픽스** | 하늘이 트인 곳에서 **3분 이내** 첫 fix(레퍼런스 `GPS_FIX_TIMEOUT_MS` 180 s와 동일 기준) |
| X3 | ★**게이팅 후 슬립 전류** | **배터리만으로** 측정해 GPS 추가 **전과 같은 수준**. +25 mA 이상 늘면 §3 실패 → 방류 금지 |
| X4 | **T1 재통과** | 배선·관통부 추가 상태로 30분 침지, Δm ≤ 0.5 g |
| X5 | **자기복원 재확인** | 추가 질량 반영해 `self_righting.py` PASS + 수조 T4(솔라면 T7) 재통과 |
| X6 | **패치 안테나 방향** | 조립 후 패치면이 위(필름-프리 창 아래)를 향함을 육안 확인 |

---

## 7. 레퍼런스(온보드 L76K) 대비 손익 — 무엇을 잃고 무엇을 얻나

### 7-1. 전력 (결론: 게이팅만 지키면 손실이 작다)

| 항목 | 레퍼런스 | 이 경로 | 판정 |
|---|---|---|---|
| 슬립 전류 | 2~12 mA | **V3V 게이팅 시 동일** / 상시 3.3V면 +30 mA | ⚠️갈림길. §3 지키면 손실 0, 틀리면 **~19일 → 2~3일 붕괴** |
| 사이클당 GPS 에너지 | L76K 콜드 30~90 s ≈ **1.5 mAh** | 구형 GPS-only(NEO-6M)면 최대 **2배(≈3 mAh)** | 🔻60분 핑 하루 132 → 168 mAh → **~19일 → ~15일(-20%)**. ★멀티 GNSS(ATGM336H·L76K)면 이 차이 대부분 소멸 |
| 모듈 LED·LDO | 없음 | 깨어있는 1~2분만 소모 | ➖무시 가능(≈2 mAh/day) |

★**Tier 1.5(솔라)에서는 위 −20%를 태양광이 덮는다** → 전력은 이 경로의 결정적 약점이 아니다.

### 7-2. 전력이 아닌 손실 (여기가 진짜)

| 손실 | 내용 | 심각도 |
|---|---|---|
| **납땜점 4개 추가**(VCC·GND·TX·RX) | 방수 기기에서 **연결부 = 누수·단선 지점**. 검수에서 지적된 최다 실패 계열 | 🔴**최대** |
| 질량 +10~20 g·부피 | CG·예비부력 변동 → `self_righting.py`·폼 재산정·F2/T4(T7) 재통과 | 🟡 |
| 안테나 자유도 하락 | 레퍼런스는 안테나가 피그테일로 나와 위치 자유. 모듈 내장 패치는 **모듈 자체를 하늘 향해** 고정해야(필름-프리 창 아래) | 🟡 |
| 미검증 | 리포의 모든 검증 수치는 온보드 L76K 기준. X1~X6를 새로 통과해야 함 | 🟡 |
| ~~구매 전 미확인~~ → **거의 해소** | GPIO 21/22 노출 여부 — §7-5 참조(공식 utilities.h에서 미사용 확인) | 🟢실물 사진 최종확인만 |

### 7-3. 이 경로가 나은 점

- 대당 약 2만 원대 절감(5대면 11~14만 원)
- **재고에 막히지 않음**(레퍼런스 변형 품절의 정면 해결책)
- **모듈만 교체 가능**(온보드 칩 고장 시 보드 전체를 버리는 것과 대비)
- 백업 배터리/슈퍼캡 있는 모듈이면 웜스타트가 빨라 **오히려 에너지 이득**

### 7-5. GPIO 21/22 노출 확인 (2026-07-27 조사)

**결론: "Without GPS" 보드에서 21·22는 비어 있고 헤더로 나와 있을 가능성이 매우 높다.** 근거 셋:

1. **LILYGO 공식 `utilities.h`의 T-A7670 정의에 21·22가 없다** — 쓰이는 핀은 모뎀(DTR 25·TX 26·RX 27·RING 33·RESET 5), 전원(PWRKEY 4·**POWERON 12**), SD(MISO 2·MOSI 15·SCK 14·CS 13), ADC(BAT 35·**SOLAR 36**)뿐. 즉 **21·22는 보드 기본 기능에 미사용 = 범용 핀.**
2. **보드 핀아웃에 21·22가 I2C 기본핀으로 표기**된다 → 도면에 있다 = **헤더로 인출**.
3. **사용자들이 21·22로 I2C를 시도한 사례**가 있고(=물리 접근 가능), "잘 안 된다"는 보고가 있는데 ★**GPS 변형에서는 L76K가 이미 그 핀을 점유**하기 때문으로 설명된다 — 우리 펌웨어 핀맵(GPS=21/22)의 역증명.

★**남은 확인**: 해당 변형의 **실물 실크스크린 사진**으로 21·22 라벨을 눈으로 확인(상품 사진 확대 또는 판매자 문의). 도면·정의는 확인했으나 그 변형의 실제 헤더 사진은 미확인.

★**공식 정의에 `BOARD_SOLAR_ADC_PIN 36`이 있다** — 태양광 입력 전압을 읽는 핀이 보드 정의에 존재한다. [TIER1_5](TIER1_5_SOLAR_DRIFTER.md) §1-3은 "문서화된 솔라 포트 없음"으로 적혀 있으나, 이 ADC 정의는 **보드에 솔라 입력 패드가 있을 가능성**을 시사한다. 사실이면 외부 충전 회로 구성이 간단해질 수 있어 **실물 도착 시 회로도·패드 확인 필수**(추정을 설계로 굳히지 말 것).

### 7-4. 권고

**첫 검증기는 레퍼런스(Built-in)** — 지금은 "설계가 되는가"를 보는 단계라 변수를 늘리면 **밀봉 실패가 설계 탓인지 추가 배선 탓인지 가릴 수 없다.** 품절로 막히면 이 경로가 정당하며, 그때는 ① **V3V 게이팅 급전** ② **멀티 GNSS 모듈 선택** ③ **1대 먼저 만들어 배터리만으로 슬립 전류 실측**(X3) 세 가지를 반드시 지킨다.

---

## 8. 정직 경계

- 이 경로는 **레퍼런스가 아니다.** 리포의 검증·수치는 온보드 L76K 변형 기준이며, **이 변형은 미검증**이다(§6 통과 전 `verified_build=false`).
- **A7670 모뎀 AT 명령으로 GNSS를 읽으려 하지 말 것**(`AT+CGNSSPWR` 등은 ERROR) — 모뎀에 GNSS가 없다. NMEA는 **모듈의 UART**에서만 온다.
- 절감액(대당 약 2만 원대)은 **납땜점 증가·부피·미검증**이라는 비용과 맞바꾸는 것이다. **첫 검증기는 가능하면 레퍼런스(Built-in) 보드**로 가고, 이 경로는 품절·비용 제약 시의 대안으로 쓴다.

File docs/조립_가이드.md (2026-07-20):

# Friendly Floaty 조립 가이드 (Tier 1 · 셀룰러 보틀) — 완전판

> **한 줄 요약**: 부품 도착 → 프린트(인필 ≤60%) → 펌웨어 플래시 → 벤치 테스트(배터리 장착!) → 조립(폼 160㎤·밸러스트 저중앙·안테나 상단) → 밀봉 → F1/F2·T1~T6 자가검증 → 방류 전 체크리스트. **테스트를 통과하지 못한 유닛은 방류하지 않는다.**

영문 개요는 [BUILD.md](BUILD.md). 근거 문서: [RELIABILITY](../hardware/RELIABILITY.md) · [FLOAT_STANDARD](../hardware/FLOAT_STANDARD.md) · [VERIFIED_BUILD_TEST](../hardware/VERIFIED_BUILD_TEST.md) · [PRELAUNCH_RECOVERY_CHECKLIST](../hardware/PRELAUNCH_RECOVERY_CHECKLIST.md) · [ELECTRONICS_POWER](../hardware/ELECTRONICS_POWER.md) · [firmware](../firmware/).

---

> ★**솔라 변형(Tier 1.5)**: 하구에 주+ 머무는 장기 잔류 임무면 배터리 단독으론 회수 전에 죽는다. 원통 감싸는 박막 셀로 보고 수명을 늘리는 변형은 [TIER1_5_SOLAR_DRIFTER](../hardware/TIER1_5_SOLAR_DRIFTER.md)를 따른다(신규 프린트 0·랩+COTS). 아래 조립에 4가지만 더한다: ①**저온 충전 컷오프(10k NTC 셀 캔 본딩, 전 모드 하드웨어 필수)** ②**비금속 RF투과 셀만**(a-Si/폴리이미드; 금속기재 금지) ③배선은 **절단-재밀봉 이음부 그로밋 재사용 → T1 재통과** ④폼 **밀도인지 +6.7 cm³/10g**로 재단. 검증은 **G5(솔라 수확)·T7(셀 장착 자기복원)·T1·F2·T6(셀 장착 RF)** 전부 통과 후 방류. 솔라는 전력이지 커버리지가 아니다(외해는 여전히 침묵). 단기 회수형이면 이 절 건너뛰고 그대로 Tier 1.

## 0. 준비물

**주문 부품(도착 대기)**
| 부품 | 확인 포인트 |
|---|---|
| LILYGO T-A7670G R2 | ★반드시 **"With GPS (L76K)"** 변형 + **A7670G**(글로벌 밴드). LTE·GNSS 안테나 2개 동봉 확인 |
| 보호회로 18650 | **연속 3A+ 정격 보호PCB**(2A 송신 피크에 OCP 트립 방지). 홀더 길이와 보호셀 길이(~69mm) 맞는지 |
| SIM | Soracom/1NCE(KT·SKT 로밍, **LG U+ 불가**) 또는 국내 KT/SKT 데이터 유심 |

**국내 즉시 조달**
| 품목 | 스펙 |
|---|---|
| PET 1L 병(재활용) | 내경 ~Ø90mm 원형(입구 넓을수록 편함). **실측해 `params.scad` 갱신** |
| 폐쇄셀 EVA/EPE 폼 | **160㎤**(예: 80×40×50mm 블록 또는 칼라 2×27mm). 다이소 매트·포장재·폐부표 OK — 단 F1 통과 필수 |
| 밸러스트 | **무연**(스테인리스 볼트·너트, 낚시 무연봉돌) **~40g**. ★납 금지(금지물질 리스트) |
| 마린/중성 실리콘 + 그로밋 | 관통부·캡 밀봉 |
| 건조제(실리카겔) | 결로 방지(F4) |
| **18650 충전기(2~4구)** | ★회수-재충전 운영의 필수 장비(역검수 추가). 보호셀 대응 확인 |
| **USB 데이터 케이블** | 충전전용 케이블은 펌웨어 업로드 불가(초심자 최다 함정) |
| 고시인성 테이프(노랑/주황) · 방수 QR/연락처 라벨 · 파라코드 | 회수성(B6) |
| 3D 프린트 3부품 | `hardware/cad/` — 브래킷·킬·회수고리. **★인필 ≤60%**(`print_infill_max`; solid로 뽑으면 폼 175㎤ 필요). PETG 권장(PLA 가능) |

**도구**: 주방저울(0.1g), 커터, 대야/양동이, 드라이버, (선택)글루건. 납땜 불필요 — 보드는 완제품.

---

## 1. 프린트 & 폼 재단

1. 병 내경을 실측해 [`params.scad`](../hardware/cad/params.scad)의 `bottle_id`를 고치고 3부품 STL 재생성(기본값 = 1L 원형 근사).
2. **인필 ≤60%로** 브래킷·킬·회수고리 출력. (실측: 3부품 solid 부피 56.9㎤ → 60%면 ~42g)
3. 폼 재단: 병에 들어갈 **160㎤**. ★**1:1 재단 템플릿**(A4 100% 인쇄·캘리브레이션 자·두께별 적층표·레이저용 DXF 포함): [uploads.caresea.kr/seacut/hardware/foam_template.html](https://uploads.caresea.kr/seacut/hardware/foam_template.html) — 10mm EVA면 **칼라당 3장×2**. 원본은 `hardware/cad/foam_collar_2d.scad`(병 규격 바꾸면 재출력). 블록형 대체는 80×40×50mm.
4. **폼 F1 소크 테스트**(소재 자격): 폼 무게 재고 → 24h 물에 눌러 담금 → 재측정. **질량 증가 <5% 합격.** 재사용/폐부표 폼은 반드시 이걸 통과해야 함.

### 1-B. ★무프린트 경로 — 3D 프린터 없이 (칼·접착만)

프린터는 전 세계 어디에나 있는 도구가 아니다. **부품의 모양이 아니라 기능을 만들면 된다**(DIY 다양성 원칙 — 커널만 지키면 껍질은 자유):

| 프린트 부품 | 기능 | 무프린트 대안 |
|---|---|---|
| 전자부 브래킷 | 보드·배터리 고정 | 폼 칼라 채널에 보드를 끼우고 **케이블타이**. 보강은 **플라스틱 골판지(단프라)/PP 판재** ㄷ자 재단 |
| 자기복원 킬 | 무게추를 배 바닥 중앙에 | 봉돌 ~40g을 지퍼백/수축튜브에 싸 **병 바닥 안쪽 중앙에 글루건+케이블타이** |
| 회수 고리 | 건질 손잡이 | 병목에 **파라코드 짧은 매듭 고리**(느슨한 올가미 금지 — 야생동물 얽힘) |

- 부력: 프린트 ~35g이 빠져 오히려 여유 증가. 단 **T2(침수부양)·T4(자기복원)는 동일하게 통과**해야 Verified Build.
- ★금지 재료: 하드보드지·골판지·MDF(물 흡수=F1 탈락), 금속(RF 차단), 개방셀 스펀지. 허용: 단프라·PP/PET 판재·EVA·케이블타이·파라코드·글루건(전 세계 문구점·철물점 조달 가능).

## 2. 펌웨어 플래시 & 벤치 (조립 전!)

> ★**조립·밀봉 전에** 전자부가 완동하는지 확인한다. 밀봉 후 발견하면 다 뜯는다.

1. Arduino IDE + ESP32 core 3.0.x, 보드 "ESP32 Dev Module". 라이브러리: **lewisxhe/TinyGSM-fork**(스톡 TinyGSM 제거!), TinyGPSPlus, ArduinoHttpClient.
2. [`drifter_a7670_cat1.ino`](../firmware/drifter_a7670_cat1/drifter_a7670_cat1.ino)에서 `DEVICE_ID`(유닛마다 고유!)·`SITE_ID`·`APN`·`SERVER_HOST` 설정. 처음엔 `BENCH_HTTP 1` + `SLEEP_MINUTES 5`.
3. **18650 장착 후** USB 연결(★USB 단독 급전은 2A 피크에서 브라운아웃 → 모뎀 고장처럼 보임).
4. 시리얼 모니터(115200)로 확인: 모뎀 응답 → 망 등록(SIM APN) → **창가/야외에서** GPS fix → POST 200.
5. **v1.1 확인 포인트**: 로그에 `seq`가 웨이크마다 1씩 증가하는지, 서버가 `ts_fix`·`sample_interval_s`를 받는지, **안테나 분리로 망을 끊고 2~3주기 돌린 뒤 복구했을 때 버퍼가 몰아서 전송되는지**(store-and-forward).
6. **★GPS 전원 관문(1차)**: fix 실패 로그에 `NMEA chars=0`이 찍히면 L76K가 모뎀 전원에 의존하는 것 — [firmware/README](../firmware/README.md)의 벤치 재검증 체크리스트 1번대로 조치. `chars>0`이면 단순 미픽스(야외로).

## 3. 조립

### 3-0. ★병 준비 — 절단·재밀봉 (QA에서 잡힌 필수 공정)

표준 페트병 입구는 **Ø28~30mm**인데 폼 칼라(Ø86)·브래킷(폭 86)은 그보다 크다 — **입구로는 물리적으로 안 들어간다.** 두 가지 길:

1. **절단-재밀봉(기본, Merlino 아르노강 방식)**: 병 어깨 아래를 커터로 깨끗이 한 바퀴 절단 → 부품 삽입·고정 → 절단부를 5~10mm 겹쳐 끼우고 **실리콘 도포 + 방수 테이프 2겹(또는 열수축 밴드)** 으로 재밀봉. ★절단부가 새 누수 지점이 되므로 **T1(밀봉 침지 30분, Δm≤0.5g)을 반드시 이 상태로** 통과시킨다.
2. **광구 용기(대안)**: 입구가 넓은 HDPE/PP 밀폐 용기(FLOAT_STANDARD 소재표)를 쓰면 절단 불필요 — 재사용·견고 캠페인에 유리.

순서(아래→위): **킬(밸러스트) → 배터리 → 폼 → 보드 → 안테나**. 원칙: 무거운 건 아래·가운데, 폼은 상부 2/3, 안테나는 최상단.

1. 킬 포켓에 밸러스트 ~40g 고정(움직이면 복원성 죽음 — 실리콘/글루로 고정). ★밸러스트를 늘리면 폼도 늘어야 함(+10g → +11.7㎤).
2. 브래킷에 보드+18650 장착, 배선 정리. 건조제 1포 동봉.
3. 폼 칼라/블록 삽입(보드 채널 통과).
4. **안테나 2개(LTE·GNSS)는 병 최상단**, 금속·물과 이격. 하우징은 비금속(RF 투과) 유지.
5. QR/연락처 라벨(방수)·고시인성 테이프(수선 위치)·회수 고리(파라코드, **저프로파일** — 야생동물 얽힘 저감) 부착.

## 3-S. 솔라 랩 시공 (Tier 1.5 · 솔라 변형만)

박막 랩은 이 변형의 **유일한 핵심 공정**이자 최다 실패모드(물속 박리·엣지 침투)다. 순서:
1. **표면 전처리** — 몸통 랩 구간 탈지(IPA) → 실란 PET 프라이머 도포 → 지정 경화시간 대기.
2. **필름 부착** — 밴드 폭 44mm, 중앙 채널 34mm(`solar_band_gap`, 회수고리·QR 노출) 유지. VHB 마린으로 리딩 엣지부터 밀착, 곡면 기포 제거.
3. **★+Z 120° 필름-프리 창** — 캡 기준 각도를 맞춰 안테나·회수고리 위 120° 섹터를 필름으로 **덮지 말 것**([assembly_solar.png](../hardware/cad/assembly_solar.png) 대조). 마스킹 테이프로 창 경계 표시 후 재단.
4. **엣지 밀봉 + ★배선 관통부** — 리드 관통·필름 가장자리를 부틸/에폭시로 밀봉(박리·침투 차단). ★필름(밖)→배터리(안) 배선은 밀봉 경계를 **반드시 관통**한다. §3-0(절단-재밀봉)은 **겹침 이음이지 배선 그로밋을 만들지 않으므로** 그것을 '재사용'할 수 없다 — 대신 (a) **캡에 IP68 케이블 글랜드 1개**를 배정하거나 (b) 절단 이음부에 **배선 포팅(에폭시) + 스트레인 릴리프**로 직접 시공한다. ★이 관통부를 포함한 상태로 **T1(30분 침지·Δm≤0.5g)을 반드시 재통과**(새 누수점)시킨다.
5. **부착물** — 충전 컨트롤러·NTC(셀 캔 본딩)·격리 다이오드는 기존 브래킷 리브에 지퍼타이(★무프린터 빌드는 폼 칼라 상부 채널 벽 또는 셀홀더 옆에 케이블타이+에폭시, CG 낮게), 벤트 패치는 캡에.

전개(flat) 절단 치수: 원주 ≈ π×`solar_wrap_od`(~289mm) · 축폭 44mm · 채널 34mm · 120° 필름-프리 호. ★정밀 SVG/DXF 전개 템플릿은 폼(`foam_collar_2d.scad`)처럼 후속 산출 예정.

## 4. 밀봉

계층 선택(RELIABILITY §7): **파일럿·회수형 = 캡+O링/실리콘**(재사용) 권장. 장기·거친 캠페인만 포팅(수리 불가).

1. 캡 나사산에 실리콘 얇게 → 체결. 관통부(있다면) 그로밋+실리콘.
2. ★**압력 균등**: 밀폐 병 + 직사광 + 리튬 = 내부 가압 위험(F2 셀벤팅). 통기벤트(Gore-Tex 패치)를 달거나, 회수형 단기 운용 + 차광(불투명 테이프 상부)으로 관리.
3. 밀봉 후 무게 실측 → 기록(질량 예산 대조: 총 ~205g 목표, RELIABILITY §1).

## 5. 자가검증 (통과 못 하면 방류 금지)

[VERIFIED_BUILD_TEST](../hardware/VERIFIED_BUILD_TEST.md)의 6종. 핵심 둘:

| 테스트 | 방법 | 합격 |
|---|---|---|
| **T1 밀봉 침지** | 30분 침지(20cm 수몰) → 개봉 없이 무게 | **Δm≤0.5g**(>2g FAIL)·내부 건조 |
| **T2 침수-부양(=F2)** | 하우징에 물 채우거나 공기배수량만큼 추 → 물에 | **72h 똑바로 부유** |
| T3 낙하 | 1.5m 콘크리트 낙하 → T1 재확인 | 밀봉 유지 |
| T4 자기복원 | 뒤집어 놓기 | 안테나가 위로 스스로 복원 |
| T5 냉수 가동 | 아이스팩 수조에서 수 주기 | 핑 누락 <10% |
| T6 소크 후 RF | T1 후 야외 | GPS+LTE 재취득 |

전부 통과 → 유닛 메타디렉토리에 `verified_build: true` 기록(스키마 §3). **이게 있어야 데이터로 인정된다.**

## 6. 방류 전·후

[PRELAUNCH_RECOVERY_CHECKLIST](../hardware/PRELAUNCH_RECOVERY_CHECKLIST.md) 전 항목 ✅ 후 방류:
- 접근 클래스 A/B/C 판정 → 회수 수단 확보(**C = 방류 금지**)
- count-in = count-out · 회수 마감 T+h · 정산 로그
- 첫 방류는 **접근 쉬운 소구간 + 짧은 테더**로 시작 권장(전 파이프라인 검증), 이후 자유 방류.

## 7. 트러블슈팅

| 증상 | 원인·해법 |
|---|---|
| 모뎀 무응답/리셋 반복 | **USB 단독 급전** → 18650 장착. 보호PCB가 2A에 트립 → 3A+ 셀로 교체 |
| 컴파일 에러 `TINY_GSM_MODEM_A7670` | 스톡 TinyGSM 설치돼 있음 → 제거하고 lewisxhe 포크만 |
| GPS fix 안 됨 | 실내 → 창가/야외. 콜드스타트 30초~3분 대기. 안테나(GNSS 쪽) 연결 확인 |
| 망 등록 실패 | APN 오타 / **LG U+ 유심**(로밍 불가) → KT·SKT 계열로 |
| 서버 400 | lat/lon 없이 POST됨(fix 실패 시 전송 안 하는 게 정상) / 스키마 필드 확인 |
| 물 새는데 뜸 | 정상 — 그게 폼 160㎤의 존재 이유. 단 그 유닛은 회수 후 재밀봉 |

---
> **정직 각주**: 모든 질량·부력·가동일수는 추정이며 빌드별 실측(위 테스트)으로 확인한다. 셀룰러(위성 아님)·물리 계산(학습 AI 아님)·회수-우선. 다수 방류 전 전파 면제확인 필요(펌웨어 헤더 참조).

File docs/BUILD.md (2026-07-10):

# Build guide (outline)

Step-by-step in the Precious Plastic Academy spirit: short steps, a photo or short clip per step. This is the outline; fill each step with a photo as you build your first unit.

## Tier 1 — Cellular Bottle

1. Gather parts. See [../hardware/BOM.md](../hardware/BOM.md). Confirm your board is the A7670 "With GPS (L76K)" variant for your region's bands.
2. Print the inserts. `../hardware/cad/` — bracket, ballast keel, recovery loop. Measure your bottle first and edit `params.scad`.
3. Flash the firmware. [../firmware/](../firmware/) with lewisxhe/TinyGSM-fork. Set APN and server URL.
4. Bench test (battery installed). Confirm modem attaches, GPS gets a fix outdoors, and one ping reaches your server (200). USB-only power will brown out; always use the 18650.
5. Assemble. Board and cell on the bracket, lead-free weight in the keel at the belly, antenna routed to the top and kept above the waterline.
6. Seal and float-test. Seal pass-throughs and the cap. Float in a tank: it should lie on its side, sit about half-submerged, and right itself antenna-up when you roll it. Adjust ballast until it does.
7. Add visibility and recovery. Bright tape at the waterline, waterproof QR/contact label, recovery loop on top.
8. Soak test 24 h. Check for leaks and condensation; confirm the battery lasts and pings keep arriving.
9. Field signal test. Walk the target stream holding the unit; confirm pings arrive in real time and your roaming SIM actually attaches.
10. Short release and recover. Release in a safe, accessible reach, track it, and recover it. Two people, life vests, a pole or net. Recover every unit.

## Tier 0 — Phone-in-a-Bottle

Reuse an old phone with GPSLogger posting to your server URL, sealed in a dry bag inside a bottle with bottom ballast and a recovery loop. This proves the whole pipeline for almost nothing, in any country. Do this first.

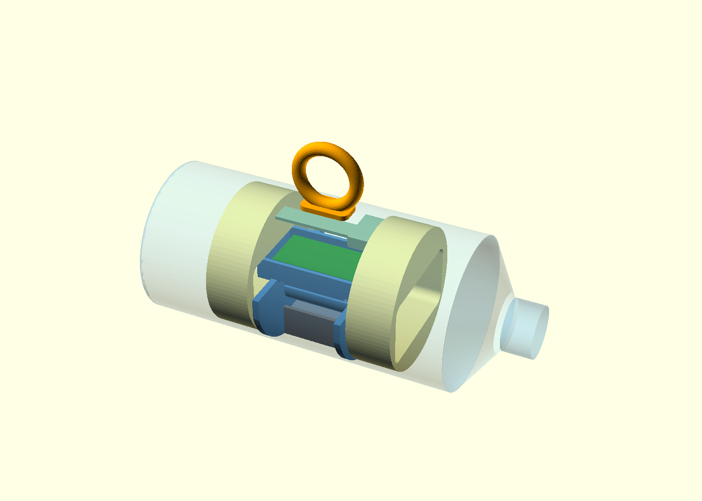
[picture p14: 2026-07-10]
hardware/cad/assembly.png

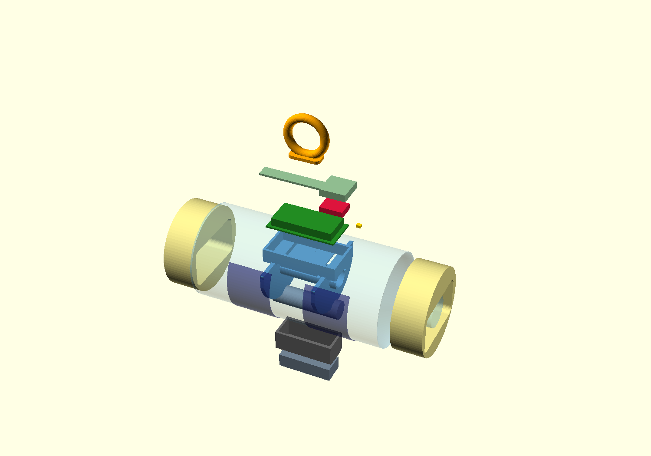
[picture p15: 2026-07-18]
hardware/cad/assembly_solar_exploded.png

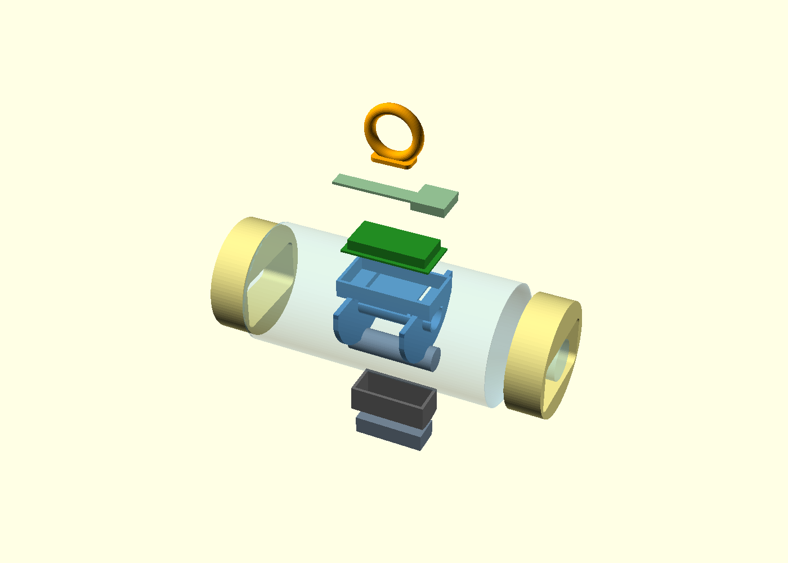
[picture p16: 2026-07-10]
hardware/cad/assembly_exploded.png

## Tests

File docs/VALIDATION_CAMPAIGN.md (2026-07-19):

# From reference design to validated project — the critical path

Everything in this repo is a **reference design**. The design, the data standard, the governance, and
the honesty guards are in place. What is **not** yet in place is the one thing that turns a design into a
project: **one real deployment with recovered units and a citable dataset.** This page is the shortest
honest path to that, written so the maintaining org can hand it to whoever runs the first water day.

The world-class review said it plainly: *design/governance/honesty are strong, but with zero built units
and zero field validation this is still a blueprint.* Nothing below is AI-doable — it is bench time,
water time, and a deposit. That is the point.

## Stage 0 — one bench unit (days, indoors)

Build a single Tier 1 unit and run the bench gates already defined in the repo. No water, no permits.

- [ ] Assemble per [BUILD.md](BUILD.md) + [../hardware/BOM.md](../hardware/BOM.md); print the three inserts.
- [ ] **F1 soak** and **F2 swamp** ([../hardware/FLOAT_STANDARD.md](../hardware/FLOAT_STANDARD.md)) — mass gain < 5%, floats upright 72 h.
- [ ] **Firmware bench loop** ([../firmware/README.md](../firmware/README.md)) with `BENCH_HTTP 1`: fix → buffer → POST 200 → sleep → wake, `seq`+1; kill coverage 2–3 cycles, confirm the buffer flushes in one batch.
- [ ] **Power (G5):** measure sleep current and the transmit peak **on battery** and replace the estimates in [../hardware/ELECTRONICS_POWER.md](../hardware/ELECTRONICS_POWER.md) with measured numbers. This is the single biggest source of "estimate → fact."
- [ ] **Self-righting (T4):** float it, roll it, time the return to antenna-up. Compare to [../hardware/SELF_RIGHTING.md](../hardware/SELF_RIGHTING.md) (predicted GM ≈ +11 mm). Update the component masses in the calculator with your measured build.
- [ ] If HTTPS: enable **TLS auth** and watch a wrong cert get **rejected** ([../firmware/README.md](../firmware/README.md) → Security). Pin the TinyGSM-fork commit.

Exit criterion: F1+F2 pass → the unit is a **Verified Float** (`verified_build:true`), and the power/righting numbers are measured, not guessed.

## Stage 1 — legal + site (parallel with Stage 0)

Only the org can do these; start them early because they gate the water day.

- [ ] **Radio.** A hand-built cellular device for outdoor multi-unit use needs the RRA research/development exemption (form 12, ≤ 1,500 units) — Korea. Elsewhere: your national radio authority, or lean on a global IoT roaming SIM. See [DEPLOY_responsibly.md](DEPLOY_responsibly.md).
- [ ] **Water manager.** Pick an **ordinary tributary reach** (managed by the city/district), not a national river / protected zone, for the first pilot. Get the sign-off. (Nakdong main channel + estuary = national + natural-monument = do **not** start there.)
- [ ] **Notify** nearby fishers / harbor / any water users so a sealed electronic box is expected, not an alarm.
- [ ] **Recovery plan.** Who retrieves, from where, with what (pole/net/boat). Recovery is the identity, not an afterthought.

## Stage 2 — the first release (one water day, a handful of units)

Small and honest. The goal is not coverage; it is **a recovered track and a measured recovery rate.**

- [ ] Release **3–10 units** over a short reach; log deploy point/time per unit ([../data/schema.md](../data/schema.md) §3 unit directory, `access_class`).
- [ ] Run the **PRELAUNCH checklist** ([../hardware/PRELAUNCH_RECOVERY_CHECKLIST.md](../hardware/PRELAUNCH_RECOVERY_CHECKLIST.md)); if minors are involved, **SAFETY_MINORS is mandatory** ([../SAFETY_MINORS.md](../SAFETY_MINORS.md)) — students never enter water, adults recover.
- [ ] Watch the live track; **recover every unit** (count-in = count-out). Record each `fate` with evidence.
- [ ] Measure: recovery rate, dwell time, real drift vs. the estimate, how often coverage dropped.

Exit criterion: ≥ 1 clean recovered trajectory, a **measured recovery rate**, and a `fate` for every unit.

## Stage 3 — make it citable (the deposit that ends "pending")

This is what lets anyone build on the work and what every "field validation pending / DOI pending" line
in this repo is waiting for.

- [ ] Export the run to standards: [../data/export_standards.py](../data/export_standards.py) → SensorThings JSON + CF-NetCDF (see [DATA_STANDARDS_CROSSWALK.md](DATA_STANDARDS_CROSSWALK.md)). Keep the `qc`/`provenance`/uncertainty flags.
- [ ] Deposit the dataset with a **DOI** (Zenodo, or SEANOE for marine) using [../CITATION.cff](../CITATION.cff). Now `obs_id` + DOI is a real citation.
- [ ] Write a short methods note (what was built, released, recovered, measured, and every honest limit from schema §4.5). A preprint or a data-paper is enough; it does not need a journal to be real.
- [ ] Update the repo: replace "estimate/pending" lines with measured values and the DOI; register the built variant ([../registry/](../registry/)).
- [ ] Only after `steward_verified` data exists is an EMODnet-style submission realistic.

## What "done" looks like

One reach, a handful of units, all recovered, one citable trajectory dataset with a DOI, and the repo's
estimates replaced by measurements. That is the moment this stops being a blueprint. Everything else in
the repo already supports it; this is the part that needs a person, a river, and an afternoon.

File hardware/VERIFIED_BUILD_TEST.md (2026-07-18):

> **한 줄 요약**: T1~T6 6종 벤치·현장 테스트를 전부 PASS해야 유닛에 `verified_build=true` 를 부여하며, 1순위는 밀봉 누수(T1)와 침수돼도 뜨는 폐쇄셀 폼 예비부력(T2)이다.

> **정직 가드 고지**: 모든 임계값은 담수(ρ≈1.0) 기준, 통신은 셀룰러(LTE Cat.1 bis, 위성 아님). 위치·상태는 물리 계산 결과이지 학습형 예측 아님. 본 문서는 절차·임계값·양식만 규정하며 **현장 실측 수치는 담지 않는다(날조 금지)**. 표의 질량·부력은 모두 **추정(estimate)**. 대원칙은 **회수-우선**.

> **연계**: 자가 공수 부력체의 성능 자격(F1 소크·F2 침수-부양)은 [FLOAT_STANDARD.md](FLOAT_STANDARD.md)에 규정되며, 여기 **T1(밀봉 누수)·T2(72h 침수-부양)** 와 연동된다. 부력체가 F1·F2를 통과해야 "Verified Float".

## 0. 왜 이 순서인가 (설계 근거)

밀봉 1L PET 병은 배수 ~1000cm³ → 부력 ~1000gf. 총질량 추정 **M_wet ≈ 207g**(밸러스트 40g 기준, RELIABILITY.md와 통일) 대비 **예비부력비 = 1000/207 ≈ 4.83× (부력/질량)** — 정상 시 안 가라앉음.
**진짜 실패모드 = 밀봉 누수 → 침수 → 공기 상실 → 고형부품(배터리·밸러스트, 물보다 무거움) 순부력 −97gf → 침몰.**
따라서 검증 1순위는 **밀봉(T1)** 과 **침수돼도 뜨는 폐쇄셀 폼 예비부력(T2)**. 폼 사이징은 정본 1.25 예비부력비식(고형 자체배수 101.9cm³ 포함) 기준 **≥155cm³ → 채택 160cm³**(RELIABILITY.md §4).

## 1. 테스트 항목·필요 장비

| # | 테스트 | 목적(실패모드) | 필요 장비(가정용) |
|---|---|---|---|
| T1 | 밀봉 침지(누수) | F1 누수 검출 | 투명 대야, 물, 주방저울(0.1g), 종이타월, 타이머 |
| T2 | 72h 부유·월파(swamp) | 침수돼도 뜨는가(폼 예비부력) | 물통/욕조, 봉수, 스포이트/주사기, 카메라 |
| T3 | 낙하·충격 | 투척·회수 낙하 시 밀봉 유지 | 줄자, 콘크리트 바닥, T1 세트 |
| T4 | 자기복원 | F6 안테나 수면 위 정렬 | 대야, 초시계, 각도기 |
| T5 | 냉수 가동 지속 | 저온 전송·브라운아웃 | 아이스팩/냉장고, 온도계, 서버 수신 로그 |
| T6 | 소크 후 RF 재취득 | 침지 후 GPS/LTE 재취득 | 실외 개활지, 스톱워치, 서버 대시보드 |

---

### T1 — 밀봉 침지(누수) 테스트 ★1순위
**절차**: ① 조립·밀봉 유닛 건조질량 m₀(0.1g) → ② 20cm 깊이 완전 수몰 30분 강제 침지 → ③ 물기 완전 제거 후 m₁ 재측정 → ④ 병 내부 응결·수적, 그로밋/실런트 이음부 육안 점검.

| 판정 | 조건 |
|---|---|
| ✅ PASS | Δm = m₁−m₀ **≤ 0.5 g** AND 내부 물방울 0 AND 내벽 응결 없음 |
| ⚠ 재작업 | 0.5g < Δm ≤ 2.0g 또는 미세 응결 → 실런트 재도포 후 재시험 |
| ❌ FAIL | Δm > 2.0g 또는 고인 물 확인 → **방류 금지** |

> 근거: 누수 2g은 이미 침수 진행, 전자부 단락 위험. 저울 0.1g 분해능으로 0.5g 문턱 판독 가능.

### T2 — 72h 부유·월파(swamp) 테스트 ★핵심
**절차**: ① 정상 밀봉으로 72h 연속 부유, 안테나부(병목) 상시 수면 위 유지·6h 간격 사진 → ② 밀봉 의도 개방, 병 내부 물 **500mL 강제 주입**(누수 최악 모사) 후 재투입 → ③ 폐쇄셀 폼 예비부력만으로 떠 있는지 관찰.

| 판정 | 조건 |
|---|---|
| ✅ PASS | (a) 72h 안테나부 상시 노출 유지 AND (b) 500mL 주입에도 **유닛 수면 잔류**(전부 수몰 안 됨) |
| ⚠ 조건부 | 500mL에서 안테나 잠기나 유닛 수면 근처 부유 → 폼 배수량 증량 후 재시험 |
| ❌ FAIL | 500mL 주입 시 **완전 침몰** → 폼 부족, 정본 사이징 재확인(≥155cm³) 후 재시험, **방류 금지** |

> 근거: 정본 사이징(폼 160cm³)은 침수 예비부력비 1.275를 보장. "침수돼도 뜬다"가 회수-우선 설계의 물리적 보증. ★고형부품 자체배수(101.9cm³)를 포함해 계산했으므로 폼 요구량은 245cm³가 아닌 160cm³다.

### T3 — 낙하·충격 테스트
**절차**: ① 밀봉 유닛 콘크리트 위 **1.5m 3회 자유낙하**(병목/밸러스트/측면 각 방향) → ② 낙하 후 즉시 **T1 침지 30분 재수행**.

| 판정 | 조건 |
|---|---|
| ✅ PASS | 병·인서트 균열 없음 AND 낙하 후 T1 Δm ≤ 0.5g |
| ❌ FAIL | 균열/밀봉 파손 또는 낙하 후 Δm > 0.5g → 방류 금지 |

### T4 — 자기복원(self-righting) 테스트
**절차**: ① 물 위에서 완전히 뒤집어(안테나부 아래로) 손 뗌 → ② 초 단위 복원시간·최종 정지 자세 사진 → ③ 5회 반복(초기 각도 다양화).

| 판정 | 조건 |
|---|---|
| ✅ PASS | 5회 모두 **≤ 5초** 자동 복원, 최종 **안테나부 수면 위** 정렬 |
| ⚠ 튜닝 | 5–10초 소요 → 밸러스트 하중/위치 튜닝(저중심 강화, +10g→폼 +11.8cm³ 트레이드오프 유의) |
| ❌ FAIL | 복원 실패 또는 안테나부 수면 아래 정착 → 밸러스트 재튜닝, 방류 금지 |

> 근거: 세장형 수직체는 복원성이 낮아(tender, 실패모드 F6) 옆으로 뜨기 쉬움. 복원팔(GM) 정량은 계산 초기값만 주고 실동작은 수조 관찰로 확정. 안테나 수면 위가 아니면 GPS·LTE 둘 다 사망.

### T5 — 냉수 가동 지속 테스트
**절차**: ① **4°C 냉수(아이스팩+물, 온도계 확인)** 부유 → ② 최소 6h(가능 시 12h) 전송 유지, 서버 수신 로그로 간격 점검 → ③ 시작·종료 배터리 전압 로그(가능 시).

| 판정 | 조건 |
|---|---|
| ✅ PASS | 4°C에서 **6h 전송 누락률 ≤ 10%** AND 전송 주기 유지 |
| ⚠ 주의 | 10–25% 누락 → Tier 2 저온 충전보호(NTC/JEITA)·벌크캡 검토 |
| ❌ FAIL | 25% 초과 누락 또는 전송 중단 → 저온 대책 없이 겨울 방류 금지 |

> 근거: 저온에서 리튬셀 용량·전류능력 저하 → 모뎀 **~2A 송신 피크**(BOM.md 명시) 브라운아웃 위험. ★반드시 배터리 장착 상태로 시험(USB 전원은 피크에서 브라운아웃, 모뎀 고장으로 오인). ※겨울 결빙 시 동결팽창(F5)은 별도 육안 검사로 병행.

### T6 — 소크 후 RF(GPS/LTE) 재취득 테스트
**절차**: ① T2 직후 또는 30분 침지 직후 실외 개활지 이동 → ② 전원 사이클 후 **콜드 스타트** TTFF·LTE attach·첫 서버 수신까지 측정 → ③ 3회 반복.

| 판정 | 조건 |
|---|---|
| ✅ PASS | 소크 후 **GPS 최초 측위 ≤ 5분** AND **LTE 첫 서버 수신 ≤ 10분**(콜드 스타트, 개활지) |
| ⚠ 주의 | GPS 5–10분 → 안테나 습기·수면 노출 재점검(F4 결로 의심) |
| ❌ FAIL | 10분 내 측위 실패 또는 서버 미수신 → 안테나 침수/실링 결함 의심, 방류 금지 |

> 근거: 온보드 L76K GNSS는 모뎀 AT GNSS가 아닌 별도 UART(NMEA/TinyGPSPlus). 셀룰러이며 위성 업링크 아님 — 음영·실내 측위 지연은 정상.

---

### T7 — 셀 장착 자기복원 (Tier 1.5 솔라 변형 전용, = T4 재시험)
**절차**: 솔라 페이로드(박막 필름 + 충전 컨트롤러 + NTC + 배선)를 전부 장착하고 폼을 `foam_vol_solar`(~186cm³)로 키운 상태에서 **T4를 그대로 재수행**. ★밸러스트는 **40g 불변**(솔라 무게 상쇄로 감량 금지 — CG 상승, 자기복원 사망).

| 판정 | 조건 |
|---|---|
| ✅ PASS | 5회 모두 ≤5초 자동 복원, 최종 안테나부 수면 위 |
| ⚠ 튜닝 | 5–10초 → 밸러스트 **위치**(질량 아님) 재튜닝 |
| ❌ FAIL | 복원 실패 또는 안테나 수면 아래 → 방류 금지 |

> 솔라 변형은 T7에 더해 **G5(솔라 수확 특성화)·T1(배선 그로밋 장착 소크)·F2(폼 `foam_vol_solar`)·T6(셀 장착 RF 재취득)** 를 추가 통과해야 한다. 상세·손익분기는 [TIER1_5_SOLAR_DRIFTER.md §4](TIER1_5_SOLAR_DRIFTER.md).

---

**Verified Build 최종 판정**: T1~T6 **전부 PASS** → `verified_build=true` 스탬프(체크리스트/스키마 연동). 하나라도 FAIL이면 방류 불가. ★**솔라 변형(Tier 1.5)은 추가로 G5+T7+T1+F2+T6(셀 장착)를 통과해야** `verified_build`.

---
> **정직 가드 각주**: 담수 기준·셀룰러(위성 아님)·물리 계산(예측 아님)·회수-우선·현장 수치 날조 금지. 모든 질량·부력은 **추정(estimate)**. 예비부력비=부력/질량으로 통일 표기.

---

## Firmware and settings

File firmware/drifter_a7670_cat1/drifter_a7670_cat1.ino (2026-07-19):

/*
 * Friendly Floaty (SEA:CUT) 드리프터 펌웨어 — LTE Cat.1 bis (A7670) + L76K GPS
 * 대상 보드: LILYGO T-A7670G R2 (With GPS L76K), ESP32-WROVER-E
 * FF-ID 스키마 v1.1 (data/schema.md) 준수.
 *
 * 동작(v1.1, store-and-forward):
 *   깨어남 → L76K GPS fix(+UTC 시각) → 레코드를 RTC 버퍼에 적재(seq 부여)
 *         → 모뎀 전원 → 망 접속(Cat.1 bis) → 버퍼의 미전송 레코드를 오래된 것부터 POST
 *         → 성공분 제거 → 딥슬립.
 *   ★망이 안 잡혀도 fix는 버퍼에 남는다(하천 음영 구간). 다음 웨이크에 몰아 보낸다.
 *   ★도착 순서를 서버가 신뢰하지 않도록 각 레코드는 자기 ts_fix(GPS UTC)와 seq를 갖고 간다.
 *   ★저전압(배터리 방전)엔 모뎀 2A 피크를 피한다: fix만 버퍼에 남기고 전송을 미룬다(하단 저전압 가드).
 *   (선행사례 공통 교훈: Duncan·Merlino·Kang 모두 store-and-forward가 필수였다.
 *    docs/사례연구_기구제작_운영_데이터.md §3-16 참조.)
 *
 * ⚠ 흐름 변경 고지: 초기 벤치 검증본(v1.0)은 "모뎀 접속 → GPS" 순서였다. v1.1은
 *   버퍼링 정합(망 없어도 fix 저장)과 모뎀 유휴 소모 절감을 위해 "GPS → 모뎀" 순서다.
 *   프리미티브(핀맵·전원 시퀀스·라이브러리)는 검증본과 동일하나, 순서 변경분은
 *   벤치 재검증 후 방류에 쓴다(정직 원칙: 측정 전 개선 주장 금지).
 *
 * ★라이브러리 (반드시): lewisxhe/TinyGSM-fork (LILYGO 공식 포크). 스톡 vshymanskyy/TinyGSM
 *   에는 TINY_GSM_MODEM_A7670 매크로가 없어 컴파일이 깨진다. 스톡이 깔려 있으면 제거한다.
 *   그 외: TinyGPSPlus, ArduinoHttpClient, Preferences(ESP32 코어 내장).
 *   보드: ESP32 Arduino core 3.0.x, "ESP32 Dev Module".
 *
 * ★GPS 주의: 이 보드의 GPS는 A7670 모뎀 내장 GNSS가 아니라 별도 Quectel L76K 칩이다.
 *   모뎀 AT(AT+CGNSSPWR/AT+CGNSSINFO)로 읽으면 ERROR가 난다. L76K 전용 UART(Serial2)의
 *   NMEA를 TinyGPSPlus로 파싱한다. 핀은 LILYGO 공식 예제 ExternalGPS_A7670G_Only 기준.
 *
 * ⚠ 법적: 자작 셀룰러 기기의 국내 실증은 전파법 적합성평가 대상이다. 다수 실증 전에
 *    국립전파연구원 연구·기술개발용 면제확인(별지 제12호, 1,500대 이하)을 받는다.
 *    1대 PoC는 국내 데이터 유심 또는 글로벌 IoT SIM으로 접속 테스트만 수행한다.
 */

// ── 전송 모드 토글 ──────────────────────────────────────────────────────────
// 1 = 벤치 검증(로컬 ingest_server.py, HTTP 평문, /api/ping).  ★처음엔 이걸로.
// 0 = 운영 전송(openc.caresea.kr, HTTPS 443, /api/observations/drift/ping).
#define BENCH_HTTP 1

// ── CONFIG ────────────────────────────────────────────────────────────────
#define DEVICE_ID     "ff-kr-bs-u0001"        // 기기 식별자(유닛 메타디렉토리 unit_id와 짝)
#define SITE_ID       "nakdong-hakjang"       // 사이트 태그(서버가 궤적에 태그)
const char* APN       = "";                   // 유심 사업자 APN. 꽂은 유심에 맞게 채운다.
                                              //  Soracom(권장 1대 PoC): "soracom.io"  (USER "sora" / PASS "sora"). 한국 KT/SKT 로밍.
                                              //  1NCE:                   "iot.1nce.net" (USER/PASS 없음). 한국 KT/SKT 로밍.
                                              //  국내 KT 알뜰폰 데이터심:  "lte.ktfwing.com"   (USER/PASS 없음)
                                              //  국내 SKT 알뜰폰 데이터심: "lte.sktelecom.com" (USER/PASS 없음)
                                              //  ※ 1NCE/Soracom 모두 LG U+ 로밍 미지원. 글로벌 IoT SIM은 KT 또는 SKT로만 붙는다.
const char* GPRS_USER = "";                   // Soracom이면 "sora"
const char* GPRS_PASS = "";                   // Soracom이면 "sora"

#if BENCH_HTTP
  // ★★보드는 Wi-Fi가 아니라 LTE(통신사 망)로 접속한다 → 통신사 NAT 뒤에서 사설 LAN IP
  //   (192.168.x.x)로는 어떤 경우에도 도달할 수 없다(QA 확정). 반드시 공인 노출:
  //   (a) `ngrok tcp 8770` → 발급된 호스트/포트를 아래에 (b) 공유기 포트포워딩+공인 IP.
  //   서버는 `python ingest_server.py 8770 0.0.0.0`으로 기동(기본은 127.0.0.1 루프백).
  //   ※ ngrok http(https 터널)는 TLS라 평문 클라이언트로 안 붙는다 → BENCH_HTTP 0으로.
  const char* SERVER_HOST = "0.tcp.ngrok.io";  // ★ngrok tcp 호스트(또는 공인 IP)로 교체
  const int   SERVER_PORT = 8770;             // ngrok tcp면 발급된 포트
  const char* SERVER_PATH = "/api/ping";
#else
  const char* SERVER_HOST = "openc.caresea.kr";
  const int   SERVER_PORT = 443;              // https
  const char* SERVER_PATH = "/api/observations/drift/ping";
#endif

const uint32_t SLEEP_MINUTES      = 30;        // 전송 주기(분). 벤치 확인은 5로 낮춰서
const uint32_t GPS_FIX_TIMEOUT_MS = 180000;    // L76K 콜드스타트 여유(야외 30초~수 분)

// ── 저전압 가드(재QA: LTE 송신 2A 피크가 방전 셀에서 브라운아웃을 일으켜 버퍼·seq를 날린다) ──
// 임계값은 벤치 실측(T3 냉수·부하시험)으로 확정한다. 아래는 18650 방전곡선 기준 보수적 초깃값.
const float    BATT_SKIP_TX_V = 3.50f;   // 이 이하: GPS fix는 남기되 모뎀(2A 피크) 생략 → 다음 주기에 몰아 전송
const float    BATT_PARK_V    = 3.30f;   // 이 이하: fix도 생략하고 장주기 park(심방전·셀 손상 방지)
const uint32_t PARK_MULT      = 4;       // park 시 슬립 배수(30분×4=2시간). 전압 회복 대기
// ───────────────────────────────────────────────────────────────────────────

// ★lewisxhe/TinyGSM-fork 전제(스톡엔 A7670 매크로 없음). TinyGsmClientSecure는
//   A76XXSSL 매크로에서만 typedef된다 → 벤치/운영을 매크로로 분기(검수에서 잡은 컴파일 불능).
#if BENCH_HTTP
  #define TINY_GSM_MODEM_A7670      // 벤치: v1.0 검증본과 동일(평문 HTTP)
#else
  #define TINY_GSM_MODEM_A76XXSSL   // 운영: TinyGsmClientSecure 포함(HTTPS). 모뎀 클래스가 바뀌므로 벤치 재검증 필수
#endif
#define TINY_GSM_RX_BUFFER 1024
#include <TinyGsmClient.h>
#include <ArduinoHttpClient.h>
#include <TinyGPSPlus.h>
#include <Preferences.h>
#include <driver/gpio.h>

// LILYGO T-A7670G R2 핀맵 (공식 utilities.h / ExternalGPS_A7670G_Only 기준)
#define MODEM_TX          26
#define MODEM_RX          27
#define BOARD_PWRKEY      4
#define BOARD_POWERON     12   // 모뎀·주변 전원 게이트. 동작 내내 HIGH 유지
#define MODEM_RST         5
#define MODEM_DTR         25
#define BOARD_BAT_ADC     35   // 배터리 전압 분압 ADC
// L76K GPS(별도 칩, Serial2). begin(baud, cfg, RX, TX) 순서 주의
#define BOARD_GPS_RX_PIN      22   // ESP32가 GPS NMEA를 받는 핀
#define BOARD_GPS_TX_PIN      21   // ESP32가 GPS로 보내는 핀
#define BOARD_GPS_WAKEUP_PIN  19   // L76K wakeup(공식 예제는 미토글, 여기선 방어적 HIGH)
#define GPS_BAUDRATE          9600

#define SerialAT  Serial1
#define SerialGPS Serial2
TinyGsm        modem(SerialAT);
#if BENCH_HTTP
TinyGsmClient        client(modem);   // 평문 HTTP
#else
TinyGsmClientSecure  client(modem);   // HTTPS(포크 SSL). 벤치 통과 후 승격
// ★★TLS-AUTH 공백(firmware/README '보안·공급망' 참조): TinyGsmClientSecure는 CA 인증서를
//   설정하지 않으면 서버 인증서를 검증하지 않는다 → 암호화는 되나 인증이 없어 MITM에 열려 있다.
//   실배포 전 setup()의 TLS-AUTH 훅에서 client.setCACert(PROD_CA_PEM)+authmode 검증을 켜고
//   ★하드웨어에서 잘못된 인증서를 '거부'하는지 실제로 확인한다(측정 전 개선 주장 금지).
static const char PROD_CA_PEM[] = "";  // ← 서버 CA/root PEM(예: ISRG Root X1). 비면 인증 미검증.
#endif
HttpClient     http(client, SERVER_HOST, SERVER_PORT);
TinyGPSPlus    gps;
Preferences    prefs;
bool           modem_on = false;   // SerialAT.begin 전 modem.poweroff() 방지 가드

// ── FF-ID v1.1 store-and-forward 버퍼 (RTC slow memory: 딥슬립 생존, 전원상실 시 소실) ──
// 전원상실(브라운아웃·배터리 교체)엔 버퍼가 사라진다 — seq는 NVS로 복원되므로 서버가
// seq 갭으로 결측을 안다(스키마 §4). NVS에 매 레코드 저장은 마모·복잡도 대비 이득이 작아
// 채택하지 않는다(정직 트레이드오프). ★저전압 가드가 송신 브라운아웃을 선제 차단해 이 소실을 줄인다.
struct PingRec {
  double   lat, lon;
  float    batt;
  float    hdop;        // <0 = 무효(필드 생략)
  uint32_t seq;
  char     ts_fix[24];  // GPS UTC ISO8601. 빈 문자열 = 시각 무효
};
#define BUF_MAX 16
RTC_DATA_ATTR PingRec  rtc_buf[BUF_MAX];
RTC_DATA_ATTR uint8_t  rtc_buf_n = 0;
RTC_DATA_ATTR uint32_t rtc_seq   = 0;   // 단조증가 레코드 카운터(딥슬립 생존)

// seq를 NVS와 동기화: 전원상실 후에도 단조증가 유지(중복 seq 방지가 목적, 갭은 허용)
uint32_t nextSeq() {
  prefs.begin("ffid", false);
  uint32_t nv = prefs.getUInt("seq", 0);
  if (nv > rtc_seq) rtc_seq = nv;       // 전원상실 직후: NVS가 최신
  rtc_seq++;
  prefs.putUInt("seq", rtc_seq);
  prefs.end();
  return rtc_seq;
}

// FF-ID v1.1 ping 본문 (data/schema.md §1).
// ts_fix = 디바이스 GPS fix 시각(관측 시각). 구서버 호환 위해 legacy "ts"도 같은 값으로 병송
// (스키마 1.0→1.1 매핑: ts → ts_fix). 서버 수신시각은 서버가 server_recv_ts로 따로 채운다.
String buildPingBody(const PingRec &r) {
  String b = String("{\"device_id\":\"") + DEVICE_ID + "\",\"site_id\":\"" + SITE_ID + "\"";
  b += ",\"seq\":" + String(r.seq);
  b += ",\"lat\":" + String(r.lat, 6) + ",\"lon\":" + String(r.lon, 6);
  b += ",\"batt\":" + String(r.batt, 2);
  b += ",\"sample_interval_s\":" + String(SLEEP_MINUTES * 60);
  if (r.hdop >= 0) b += ",\"fix_quality\":" + String(r.hdop, 1);
  b += ",\"gnss_source\":\"l76k\"";
  if (r.ts_fix[0]) { b += ",\"ts_fix\":\"" + String(r.ts_fix) + "\",\"ts\":\"" + String(r.ts_fix) + "\""; }
  b += "}";
  return b;
}

// 배터리 전압(V): 100k/100k 분압 가정. analogReadMilliVolts로 eFuse Vref 교정(재QA #3:
// raw*3.3/4095는 ADC 비선형·Vref 편차로 저전압 판정이 수십 mV 어긋난다 → 밀리볼트 API가 교정 내장).
// 저전압 컷오프가 이 값에 걸리므로 교정이 가드의 전제다.
float readBatteryV() {
  uint32_t mv = 0;
  for (int i = 0; i < 16; i++) mv += analogReadMilliVolts(BOARD_BAT_ADC);
  mv /= 16;
  return (mv / 1000.0f) * 2.0f;  // 분압 2배
}

void modemPowerOn() {
  pinMode(BOARD_POWERON, OUTPUT); digitalWrite(BOARD_POWERON, HIGH);
  // ★T-A7670 계열 RST는 HIGH=리셋 어서트(공식 utilities.h MODEM_RESET_LEVEL=HIGH). 유휴=LOW.
  //   (검수에서 잡은 v1.0 계승 버그: HIGH로 방치하면 모뎀이 리셋에 잡혀 testAT 전패)
  pinMode(MODEM_RST, OUTPUT);
  digitalWrite(MODEM_RST, LOW);  delay(100);
  digitalWrite(MODEM_RST, HIGH); delay(2600);   // 하드 리셋 펄스(공식 시퀀스)
  digitalWrite(MODEM_RST, LOW);                 // 반드시 LOW로 종료
  pinMode(BOARD_PWRKEY, OUTPUT);
  digitalWrite(BOARD_PWRKEY, LOW);  delay(100);
  digitalWrite(BOARD_PWRKEY, HIGH); delay(1000);  // PWRKEY 펄스
  digitalWrite(BOARD_PWRKEY, LOW);
  modem_on = true;
}

// L76K GPS(Serial2)에서 NMEA를 읽어 위경도 취득. 성공 시 true.
// ★모뎀 AT가 아니라 L76K UART다. 실내에서는 대부분 fix 안 됨 → 창가/야외에서 확인.
// ★GPS 전원은 BOARD_POWERON 레일에 걸려 있어 fix 전에 POWERON을 먼저 HIGH로 올린다.
bool getFix(double &lat, double &lon, uint32_t timeoutMs = GPS_FIX_TIMEOUT_MS) {
  pinMode(BOARD_POWERON, OUTPUT); digitalWrite(BOARD_POWERON, HIGH);  // GPS 레일 확보(모뎀보다 먼저 필요)
  pinMode(BOARD_GPS_WAKEUP_PIN, OUTPUT); digitalWrite(BOARD_GPS_WAKEUP_PIN, HIGH);
  SerialGPS.begin(GPS_BAUDRATE, SERIAL_8N1, BOARD_GPS_RX_PIN, BOARD_GPS_TX_PIN);
  uint32_t start = millis();
  while (millis() - start < timeoutMs) {
    while (SerialGPS.available()) gps.encode(SerialGPS.read());
    bool locOk  = gps.location.isValid() && gps.location.age() < 3000 && gps.satellites.value() >= 4;
    bool timeOk = gps.date.isValid() && gps.time.isValid() && gps.date.year() >= 2025;
    if (locOk && timeOk) {           // RMC(날짜)는 같은 에포크에 오므로 지연 최대 ~1초.
      lat = gps.location.lat();      // 날짜 검증 없이 리턴하면 ts_fix가 비어 서버가 server_recv로
      lon = gps.location.lng();      // 강등 — 버퍼 지연 레코드는 관측시각이 통째로 틀어짐(검수 발견)
      return true;
    }
    delay(10);
  }
  // 타임아웃 폴백: 위치만이라도 유효하면 관측은 살린다(ts_fix만 결측 → 서버가 server_recv 강등)
  if (gps.location.isValid() && gps.location.age() < 3000 && gps.satellites.value() >= 4) {
    lat = gps.location.lat(); lon = gps.location.lng();
    return true;
  }
  // 진단: chars=0이면 GPS 무전원/배선(POWERON 레일 전제 확인 — 벤치 1차 관문), >0이면 단순 미픽스
  Serial.printf("[FF] GPS fix 실패: NMEA chars=%lu\n", (unsigned long)gps.charsProcessed());
  return false;
}

// GPS UTC 시각을 ISO8601로. 유효하지 않으면 빈 문자열.
void gpsIso8601(char* buf, size_t n) {
  if (gps.date.isValid() && gps.time.isValid() && gps.date.year() >= 2025) {
    snprintf(buf, n, "%04d-%02d-%02dT%02d:%02d:%02dZ",
             gps.date.year(), gps.date.month(), gps.date.day(),
             gps.time.hour(), gps.time.minute(), gps.time.second());
  } else {
    buf[0] = '\0';
  }
}

// 버퍼 적재. 가득 차면 가장 오래된 것을 버리고 최신을 지킨다(현재 위치 우선, 스키마 §4가
// seq 갭으로 결측을 안다). GDP식 운명 기록은 서버·정산 로그가 담당.
void bufPush(const PingRec &r) {
  if (rtc_buf_n >= BUF_MAX) {
    memmove(&rtc_buf[0], &rtc_buf[1], sizeof(PingRec) * (BUF_MAX - 1));
    rtc_buf_n = BUF_MAX - 1;
  }
  rtc_buf[rtc_buf_n++] = r;
}

// 버퍼 앞에서부터(오래된 순) POST. 2xx면 제거, 실패하면 중단(남은 건 다음 웨이크에).
// 반환: 보낸 개수.
int flushBuffer() {
  int sent = 0;
  while (rtc_buf_n > 0) {
    String body = buildPingBody(rtc_buf[0]);
    Serial.println("[FF] POST " + body);
    http.beginRequest();
    http.post(SERVER_PATH);
    http.sendHeader("Content-Type", "application/json");
    http.sendHeader("Content-Length", body.length());
    http.beginBody();
    http.print(body);
    http.endRequest();
    int status = http.responseStatusCode();
    if (status > 0) http.responseBody();   // 유효 응답만 소진(오류코드면 재차 30초 대기 회피)
    Serial.print("[FF] 서버 응답 "); Serial.println(status);
    if (status >= 200 && status < 300) {
      memmove(&rtc_buf[0], &rtc_buf[1], sizeof(PingRec) * (rtc_buf_n - 1));
      rtc_buf_n--; sent++;
    } else {
      http.stop();
      break;               // 실패: 배터리 아끼고 다음 주기에 재시도
    }
  }
  return sent;
}

// 지정 분(minutes)만큼 딥슬립. 모뎀·L76K 전원을 끊고(POWERON LOW) GPIO를 홀드해 슬립 중
// 누설을 막는다 — L76K 저전력화는 별도 백업명령이 아니라 이 POWERON 레일 차단으로 달성(절감폭 실측 전).
void deepSleepFor(uint32_t minutes) {
  if (modem_on) modem.poweroff();
  // 딥슬립 중 일반 GPIO는 플로팅 → GPS_WAKEUP이 HIGH로 남으면 L76K가 슬립 내내 켜져
  // 배터리를 지배할 수 있다(공식 DeepSleep 예제 방식으로 홀드). 절감폭은 실측 전.
  pinMode(BOARD_GPS_WAKEUP_PIN, OUTPUT); digitalWrite(BOARD_GPS_WAKEUP_PIN, LOW);
  gpio_hold_en((gpio_num_t)BOARD_GPS_WAKEUP_PIN);
  pinMode(MODEM_RST, OUTPUT);            digitalWrite(MODEM_RST, LOW);
  gpio_hold_en((gpio_num_t)MODEM_RST);
  pinMode(BOARD_POWERON, OUTPUT);        digitalWrite(BOARD_POWERON, LOW);
  gpio_hold_en((gpio_num_t)BOARD_POWERON);
  gpio_deep_sleep_hold_en();
  esp_sleep_enable_timer_wakeup((uint64_t)minutes * 60ULL * 1000000ULL);
  esp_deep_sleep_start();
}

// 표준 주기 딥슬립(기존 호출부 호환)
void deepSleep() { deepSleepFor(SLEEP_MINUTES); }

void setup() {
  // 웨이크 직후 홀드 해제(없으면 이후 digitalWrite가 홀드에 막혀 무효)
  gpio_deep_sleep_hold_dis();
  gpio_hold_dis((gpio_num_t)BOARD_GPS_WAKEUP_PIN);
  gpio_hold_dis((gpio_num_t)MODEM_RST);
  gpio_hold_dis((gpio_num_t)BOARD_POWERON);
  Serial.begin(115200);
  analogReadResolution(12);
  // 리셋 사유 로깅(재QA #5): 브라운아웃(ESP_RST_BROWNOUT=6)이 반복되면 저전압 가드·전원설계 재검토 신호
  Serial.printf("[FF] reset_reason=%d (3=SW 4=panic 6=BROWNOUT 8=deepsleep)\n", (int)esp_reset_reason());

  // ★저전압 park(모뎀·GPS 켜기 전에 먼저): 심방전 구간이면 아무 동작 없이 장주기로 자 셀을 보호한다.
  float vbat0 = readBatteryV();
  if (vbat0 > 1.0f && vbat0 < BATT_PARK_V) {   // >1.0V = 측정 유효(USB 급전·미장착 오검 배제)
    Serial.printf("[FF] 저전압 park %.2fV<%.2fV → %lu분 슬립\n",
                  vbat0, BATT_PARK_V, (unsigned long)(SLEEP_MINUTES * PARK_MULT));
    deepSleepFor(SLEEP_MINUTES * PARK_MULT);
  }

  // ① GPS fix 먼저(망 없어도 관측은 남긴다 — store-and-forward의 요점)
  double lat = 0, lon = 0;
  bool fixed = getFix(lat, lon);
  if (fixed) {
    PingRec r;
    r.lat = lat; r.lon = lon;
    r.batt = readBatteryV();
    r.hdop = gps.hdop.isValid() ? (float)gps.hdop.hdop() : -1.0f;
    r.seq  = nextSeq();
    gpsIso8601(r.ts_fix, sizeof(r.ts_fix));
    bufPush(r);
    Serial.printf("[FF] fix seq=%lu lat=%.6f lon=%.6f hdop=%.1f sats=%lu batt=%.2fV buf=%u\n",
                  (unsigned long)r.seq, lat, lon, r.hdop, gps.satellites.value(), r.batt, rtc_buf_n);
  } else {
    Serial.println("[FF] GPS fix 실패(실내면 창가/야외로). 버퍼 있으면 전송만 시도");
  }

  if (rtc_buf_n == 0) {         // 보낼 것도 없음 → 바로 슬립
    Serial.println("[FF] 전송할 레코드 없음 → 슬립");
    deepSleep();
  }

  // ★저전압이면 모뎀(2A 피크)을 켜지 않는다: fix는 버퍼에 남았으니 전압 회복 후 다음 주기에 몰아 보낸다.
  //   송신 도중 브라운아웃이 버퍼·seq를 통째로 날리는 것보다, 늦더라도 관측을 지키는 편이 낫다(재QA).
  float vbat = readBatteryV();
  if (vbat > 1.0f && vbat < BATT_SKIP_TX_V) {
    Serial.printf("[FF] 저전압 %.2fV<%.2fV → 전송 보류(버퍼 %u건 보존), 슬립\n",
                  vbat, BATT_SKIP_TX_V, rtc_buf_n);
    deepSleep();
  }

  // ② 모뎀 → 망 → 버퍼 플러시
  modemPowerOn();
  SerialAT.begin(115200, SERIAL_8N1, MODEM_RX, MODEM_TX);  // 공식 예제와 동일(RX,TX 순서)
  delay(3000);

  Serial.println("[FF] 모뎀 초기화");
  if (!modem.testAT(10000)) {
    // 무응답이면: (1) 18650 배터리 장착(USB만 급전 금지) (2) BOARD_POWERON HIGH (3) baud 115200
    Serial.println("[FF] 모뎀 무응답 → 관측은 버퍼에 보존, 슬립");
    deepSleep();
  }
  if (!modem.waitForNetwork(60000)) { Serial.println("[FF] 망 등록 실패 → 버퍼 보존, 슬립"); deepSleep(); }
  if (!modem.gprsConnect(APN, GPRS_USER, GPRS_PASS)) { Serial.println("[FF] PDP 실패(APN 확인) → 버퍼 보존, 슬립"); deepSleep(); }
  Serial.print("[FF] 접속 IP "); Serial.println(modem.getLocalIP());

  // ★★TLS-AUTH 훅(운영 HTTPS): 첫 connect 전에 CA를 심고 서버 인증서 검증을 켠다.
  //   아래는 하드웨어 검증 전이라 주석 처리 — README '보안·공급망' 절차대로 켜고 벤치에서
  //   잘못된 인증서 '거부'를 확인한 뒤에만 실데이터를 보낸다. authmode/SNI는 포크 SSL API에 따름.
  // #if !BENCH_HTTP
  //   if (PROD_CA_PEM[0]) client.setCACert(PROD_CA_PEM);   // 없으면 인증 미검증(MITM 취약)
  //   // + AT+CSSLCFG "authmode"=서버검증, "sni"/"servername"=SERVER_HOST (포크 SSL 설정)
  // #endif

  int sent = flushBuffer();
  Serial.printf("[FF] 전송 %d건, 잔여 %u건\n", sent, rtc_buf_n);

  modem.gprsDisconnect();
  Serial.println("[FF] 완료 → 딥슬립");
  deepSleep();
}

void loop() { /* 딥슬립 사용, loop 미사용 */ }

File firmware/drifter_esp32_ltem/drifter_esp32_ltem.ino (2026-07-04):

/*
 * SEA:CUT GPS 드리프터 펌웨어 스켈레톤 — ESP32 + GPS + LTE-M(SIM7080G)
 * ===================================================================
 * 패턴: 깨어남 → GPS fix → LTE-M로 좌표 POST → deep sleep.
 *   간헐 전송(예: 5분 주기)으로 배터리를 아낀다. 상시연결을 버린 게 이득.
 *
 * 전송 대상(둘 중 택1, 아래 POST_URL):
 *   1) SEA:CUT 수신 서버  POST /api/ping
 *        body {"device_id","lat","lon","ts"}   (ingest_server.py 스키마)
 *   2) openc.caresea.kr   POST /api/observations/drift  (DriftTrack, 궤적 누적형)
 *   스켈레톤은 1)을 기본으로 한다.
 *
 * 라이브러리(Arduino 라이브러리 매니저):
 *   - TinyGPSPlus      (GPS NMEA 파싱)
 *   - TinyGSM          (SIM7080 등 셀룰러 모뎀 AT 래퍼)  #define 아래 참고
 *
 * ★하드웨어 주의: NodeMCU/데브보드는 잠들어도 USB칩·레귤레이터가 전류를 샌다.
 *   실운용은 베어 ESP32 모듈 + GPS/모뎀 전원 게이팅(MOSFET) + (선택) 소형 태양광.
 *   시연용은 보조배터리로 충분.
 *
 * ⚠ 스켈레톤이다. 핀맵·APN·URL·전원게이팅을 실제 보드에 맞춰 채우고 검증할 것.
 */

#define TINY_GSM_MODEM_SIM7080          // 모뎀 종류(SIM7080G = LTE-M/NB-IoT)
#include <TinyGsmClient.h>
#include <TinyGPSPlus.h>

// ---------- 설정(확정 필요) -------------------------------------------------
static const char* DEVICE_ID = "DRIFTER-01";
static const char* APN        = "lte-m.sktelecom.com";   // ★통신사 LTE-M APN으로 교체(SKT/KT)
static const char* POST_HOST  = "openc.caresea.kr";      // 또는 수신 서버 호스트/IP
static const int   POST_PORT  = 443;                     // https=443, 로컬 http=8770 등
static const char* POST_PATH  = "/api/observations/drift/ping"; // 엔드포인트 경로
static const bool  USE_TLS    = true;

static const uint64_t WAKE_INTERVAL_S = 300;   // 전송 주기(초). 5분=300
static const uint32_t GPS_FIX_TIMEOUT_MS = 90000;  // GPS fix 최대 대기(콜드스타트 여유)

// 핀맵(★보드에 맞게) — GPS=UART1, 모뎀=UART2, 전원 게이팅 핀
static const int PIN_GPS_RX = 16, PIN_GPS_TX = 17;
static const int PIN_MODEM_RX = 26, PIN_MODEM_TX = 27, PIN_MODEM_PWR = 4;
static const int PIN_GPS_EN = 2;   // GPS 전원 MOSFET 게이트(HIGH=on)

// ---------------------------------------------------------------------------
HardwareSerial SerialGPS(1);
HardwareSerial SerialModem(2);
TinyGPSPlus gps;
TinyGsm modem(SerialModem);
TinyGsmClient  gsmPlain(modem);
#ifdef TINY_GSM_MODEM_HAS_SSL
TinyGsmClientSecure gsmSecure(modem);
#endif

static void sleepNow() {
  digitalWrite(PIN_GPS_EN, LOW);       // GPS 끄기
  modem.poweroff();                    // 모뎀 끄기
  esp_sleep_enable_timer_wakeup(WAKE_INTERVAL_S * 1000000ULL);
  Serial.println("deep sleep...");
  Serial.flush();
  esp_deep_sleep_start();              // 여기서 잔다. 깨면 setup()부터 다시.
}

// GPS fix 대기 → 성공 시 lat/lon 채우고 true
static bool getFix(double& lat, double& lon) {
  digitalWrite(PIN_GPS_EN, HIGH);
  SerialGPS.begin(9600, SERIAL_8N1, PIN_GPS_RX, PIN_GPS_TX);
  uint32_t t0 = millis();
  while (millis() - t0 < GPS_FIX_TIMEOUT_MS) {
    while (SerialGPS.available()) gps.encode(SerialGPS.read());
    if (gps.location.isValid() && gps.location.age() < 3000 && gps.satellites.value() >= 4) {
      lat = gps.location.lat();
      lon = gps.location.lng();
      return true;
    }
    delay(20);
  }
  return false;
}

// 모뎀 켜기 → 망 접속
static bool modemConnect() {
  pinMode(PIN_MODEM_PWR, OUTPUT);
  digitalWrite(PIN_MODEM_PWR, HIGH); delay(1200); digitalWrite(PIN_MODEM_PWR, LOW);
  SerialModem.begin(115200, SERIAL_8N1, PIN_MODEM_RX, PIN_MODEM_TX);
  delay(3000);
  if (!modem.restart()) return false;
  if (!modem.waitForNetwork(60000)) return false;
  if (!modem.gprsConnect(APN, "", "")) return false;
  return true;
}

// 좌표를 JSON으로 POST. 성공 시 true
static bool postFix(double lat, double lon) {
  TinyGsmClient* client = &gsmPlain;
#ifdef TINY_GSM_MODEM_HAS_SSL
  if (USE_TLS) client = (TinyGsmClient*)&gsmSecure;
#endif
  if (!client->connect(POST_HOST, POST_PORT)) return false;

  // ISO8601 타임스탬프(UTC) — GPS 시각 사용
  char ts[32] = "";
  if (gps.date.isValid() && gps.time.isValid()) {
    snprintf(ts, sizeof(ts), "%04d-%02d-%02dT%02d:%02d:%02dZ",
             gps.date.year(), gps.date.month(), gps.date.day(),
             gps.time.hour(), gps.time.minute(), gps.time.second());
  }
  char body[160];
  int n = snprintf(body, sizeof(body),
    "{\"device_id\":\"%s\",\"lat\":%.6f,\"lon\":%.6f,\"ts\":\"%s\"}",
    DEVICE_ID, lat, lon, ts);

  client->printf("POST %s HTTP/1.1\r\n", POST_PATH);
  client->printf("Host: %s\r\n", POST_HOST);
  client->print("Content-Type: application/json\r\n");
  client->printf("Content-Length: %d\r\n", n);
  client->print("Connection: close\r\n\r\n");
  client->print(body);

  uint32_t t0 = millis();
  while (client->connected() && millis() - t0 < 15000) {
    if (client->available()) { String line = client->readStringUntil('\n'); if (line.startsWith("HTTP/")) { Serial.println(line); break; } }
  }
  client->stop();
  return true;
}

void setup() {
  Serial.begin(115200);
  pinMode(PIN_GPS_EN, OUTPUT);
  Serial.printf("\n[%s] wake\n", DEVICE_ID);

  double lat, lon;
  if (!getFix(lat, lon)) { Serial.println("GPS fix 실패 → sleep"); sleepNow(); }
  Serial.printf("fix %.6f, %.6f (sats %lu)\n", lat, lon, gps.satellites.value());

  if (modemConnect() && postFix(lat, lon)) Serial.println("POST 완료");
  else Serial.println("전송 실패(다음 주기 재시도)");

  sleepNow();
}

void loop() { /* deep sleep 패턴이라 loop는 비움 */ }

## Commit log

2026-07-04 SEA:CUT — 소하천 Physical AI 오픈소스 초기 공개
    시민과학 하천 부유쓰레기 표류 관측 + 퇴적 핫스팟 발견.
    - 표류 모델: OpenDrift 데모 + numpy 경량본 + 예측 GeoJSON
    - 웹 데모: 홈·SLM 시뮬·낙동강 표류 지도
    - 참여자 PWA + 드리프터 펌웨어(ESP32/GPS/LTE-M)·BOM
    - API 키 미포함(MOF_KEY 환경변수), MIT License
    운영: 사단법인 이타서울 · GAA
2026-07-10 Add open-hardware BOM, parametric 3D parts, and build/deploy docs
    - Tiered BOM (Tier 0/1/2) and global open-hardware guide (EN/KO)
    - Parametric OpenSCAD parts (bracket, ballast keel, recovery loop) + STL and assembly preview
    - Verified LILYGO T-A7670G firmware (drifter_a7670_cat1); SIM7080 skeleton marked deprecated
    - Data schema, build guide, responsible-deploy localize checklist
    - CERN-OHL-P (hardware) and CC BY 4.0 (docs/data) licenses; OSHWA-ready
    - Correct README hardware stack to cellular A7670 (Cat.1 bis) + onboard L76K
    [assembly.scad, ballast_keel.scad, ballast_keel.stl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]
2026-07-10 Switch to ShareAlike licensing and upgrade data schema
    - Hardware CERN-OHL-S v2 (strongly reciprocal), docs/data CC BY-SA 4.0;
    firmware/software stays MIT. Improvements to designs, docs, data stay open.
    - Upgrade data/schema.md to the citable Friendly Floatee standard:
    obs_id, provenance/verification, calibration commons, citation format.
2026-07-10 hardware: add reliability, verified-build test, recovery protocol, AI/CAD tooling
    Grounded against the current Tier-1 BOM, adversarially verified:
    - RELIABILITY.md: sealed reserve buoyancy ~4.83x; flooded net buoyancy ~-97 gf
    (real failure mode) reversed by ~160 cm^3 closed-cell foam; self-righting and
    ballast/foam tradeoff (+10 g ballast -> +~11.7 cm^3 foam); failure modes F1-F7.
    - VERIFIED_BUILD_TEST.md: 6 self-check tests (seal soak, 72h swamp, drop,
    self-right, cold endurance, RF-after-soak) with pass/fail thresholds.
    - PRELAUNCH_RECOVERY_CHECKLIST.md: no-recovery-no-launch; count-in = count-out;
    access-class A/B/C decision tree; recovery-provider registry; provenance gate.
    - doc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
    [params.scad]
2026-07-10 hardware: add FLOAT_STANDARD (self-sourced buoyancy body, performance-based)
    Standardize the spec, not the material (Precious Plastic style): builders
    self-source any float locally (upcycle-first) and qualify it with two field
    tests — F1 soak (closed-cell, <5% mass gain) and F2 flooded-float (72h upright).
    Cross-referenced with VERIFIED_BUILD_TEST T1/T2 and the provenance gate.
2026-07-10 hardware: add ELECTRONICS_POWER (power budget, device-class matrix, solar option)
    Grounded against the Tier-1 BOM (18650 + LILYGO T-A7670G R2), adversarially verified:
    - Power budget: modem keep-alive vs power-cycle branches (they cross over by ping
    interval). Room-temp estimates ~1.6-4d @5min, ~3.5-7.4d @15min, ~6.3-18.9d @60min;
    cold-water derate; all estimates pending bench measurement. (Prior "52d @60min"
    overclaim removed — it assumed hardware mods not in the BOM.)
    - Mission device-class matrix: Class 1 river-recoverable (our BOM, cellular) /
    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
2026-07-10 docs: DIY diversity framework + prior-art case study; measured reliability refinements
    - docs/DIY_DIVERSITY.md — community open-DIY architecture (small fixed kernel + wide
    free shell), adversarially critiqued. 4 kernels (K1 data schema, K2 recover-first,
    K3 Verified Float, K4 honest labels) with minimum contracts; closed real loopholes
    (CRS lock, dual timestamp anti-teleport, sample-interval declaration, stranded
    marker, recovery cross-verification, B8/B9 float safety, banned-substance hardlist,
    wildlife-safe recovery loop). Free-shell catalog, Tier-0 on-ramp, registry,
    self-cert badge, localization hard-gates.
    - docs/사례연구_기구제작_운영_데이터.md — prior-art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
    [params.scad]
2026-07-10 data: FF-ID schema v1.1 — adopt prior-art data practices
    Reflects lessons from the prior-art study (NOAA GDP, OpenMetBuoy, Duncan, Merlino, Kang):
    - Dual timestamp: ts_fix (device GPS fix) vs server_recv_ts + ts_source flag
    (blocks store-and-forward "teleport" fake trajectories).
    - seq: monotonic per-device record counter for store-and-forward ordering/dedup.
    - sample_interval_s required (mixed-cadence weighting); fix_quality + gnss_source.
    - CRS lock EPSG:4326, lat/lon >=5 decimals.
    - Unit metadata directory (GDP-style): deploy/end coords+ts, fate/death code,
    hardware, verified_build; fate=recovered requires last_gps + heartbeat evidence.
    - QC: 2-stage 4-sigma velocity (Hansen & Poula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
2026-07-10 firmware: FF-ID v1.1 store-and-forward + assembly guide; fix two inherited critical bugs
    Firmware (drifter_a7670_cat1.ino), adversarially reviewed (3 lenses + adjudicator),
    all confirmed findings applied:
    - v1.1 flow: GPS fix FIRST -> RTC ring buffer (16 rec) with monotonic seq
    (RTC + NVS backed) -> modem -> flush oldest-first. A cellular dead zone no
    longer loses observations (store-and-forward — common lesson from Duncan/
    Merlino/Kang prior art).
    - v1.1 payload: ts_fix (GPS UTC observation time) + legacy ts, sample_interval_s,
    fix_quality (HDOP), gnss_source, seq.
    - FIX (critical, inherited from v1.0): MODEM_RST polarity — T-A7670 RST is
    HIGH=assert (official MODEM_RESET_LEV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
    [drifter_a7670_cat1.ino]
2026-07-10 server: ingest v1.1 (store-and-forward ready) + 5-unit bench checklist
    ingest_server.py — FF-ID v1.1, dry-run verified against simulated board POSTs:
    - /api/ping accepts and stores seq, ts_fix, sample_interval_s, fix_quality,
    gnss_source, batt, site_id, motion_state (v1.0 "ts" maps to ts_fix;
    missing time degrades to ts_source=server_recv).
    - Idempotent (device_id, seq): a store-and-forward retry after a lost 2xx
    returns dup:true instead of double-storing.
    - Track assembly orders by ts_fix then seq — never trusts arrival order
    (verified: arrival 1,3,2 assembles as 1,2,3).
    - live_now point exposes seq/batt/ts_source/fix_quality for bench monitoring.
    - Bind configurable (arg/env):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
2026-07-10 cad: complete real-size full assembly (mech + comms + foam + all BOM parts)
    - foam_collar.scad — the flooded-reserve buoyancy part promoted from variables to
    an actual CUT-master model (2 collars ~160 cm3 EVA; payload channel 70x40 clears
    the bracket tray, cell holder and keel; RELIABILITY §4 numbers preserved).
    - mockups.scad — real-size stand-ins: 1L bottle shell (~O92x230 with neck/cap),
    LILYGO T-A7670G (68x34x12), protected 18650 (O18.6x68), lead-free ballast pack,
    LTE FPC + GNSS patch antennas.
    - assembly.scad — full deployed assembly with an `explode` parameter
    (-D explode=1 renders the exploded view); collision-checked renders committed
    (assembly.png / assembly_expl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
    [asm_antennas.stl, asm_ballast.stl, asm_board.stl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]
2026-07-10 cad: foam collar 1:1 cut template (SVG print / DXF laser) from the same source
    - foam_collar_2d.scad — the collar cross-section projected to 2D from the same
    parametric source (single source of truth; change params.scad, re-export).
    - foam_collar_template.svg — true-mm (86mm) SVG, prints 1:1 at 100% scale.
    - foam_collar_template.dxf — laser/CNC cutting.
    - Printable A4 page with calibration ruler, per-thickness layer table
    (10mm EVA -> 3 sheets per collar x2 = ~182 cm3) and 6-step cutting guide
    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
    [foam_collar_2d.scad, foam_collar_template.dxf]
2026-07-11 cad: fix license header mismatch and false STEP-export claim (audit findings)
    - params.scad header said CERN-OHL-P / CC BY, contradicting the canonical
    LICENSE-hardware.md (CERN-OHL-S v2) and LICENSE-docs.md (CC BY-SA 4.0).
    Headers are what people copy — now they match the license files.
    - cad/README claimed `openscad --export-format=step` [2024+]; verified against
    the actual toolchain: OpenSCAD is mesh-based CSG and cannot export BREP STEP.
    Replaced with an honest note (3MF for mesh interchange; FreeCAD conversion is
    lossy; the OpenSCAD source is the editable master per OSHWA).
    [params.scad]
2026-07-11 docs+server: gap register w/ resolutions, QA-panel fixes, QC reference impl, registries
    Gap register (구멍_목록.md, new) — living document of known gaps with statuses;
    filled items are kept with evidence (honesty: gaps are never hidden).
    Resolved this round (구멍_해결_2026-07-11.md, new — 7 research/draft resolutions):
    - A2 CONFIRMED from official schematics: L76K VCC sits on the V3V rail gated by
    GPIO12 (BOARD_POWERON) OR USB VBUS — independent of the modem. GPS-first holds.
    Bench must verify on battery only (VBUS masks the gate). firmware/README updated.
    - A3/A5: battery ADC divider confirmed 100k/100k (factor 2.0); deep-sleep range
    narrowed with official/community mea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
2026-07-11 firmware: fix bench-server comment — LAN private IP can never work over LTE
    QA panel confirmed the v1.0-inherited comment offering "(a) same-network laptop
    LAN IP" as a bench path is physically impossible: the board connects over the
    carrier LTE network (behind carrier NAT), so a private 192.168.x.x address is
    unreachable in every case. Comment now mandates ngrok tcp or router
    port-forwarding + public IP, and documents the 0.0.0.0 server bind.
    [drifter_a7670_cat1.ino]
2026-07-11 docs: dependency map + domestic-precedent comparison; fix stale LTE-M label
    - DEPENDENCIES.md (new): what we depend on, why, and the substitute path for each.
    Core (schema/recovery/buoyancy/honesty) has ZERO external deps; OpenDrift is an
    optional analysis aid (Kang 2025 proved it is replaceable); the only real
    single-point dependency is the firmware TinyGSM-fork, and even that is bypassed
    by the DIY-diversity rule (firmware is a free shell — any library works if it
    POSTs the schema). No vendor API lock-in.
    - Case study: added a head-to-head Jeju/Han-river vs us comparison table (scale,
    electronics/comms, data, recovery, openness) and a windage-borrowing caveat —
    Kang's alp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
2026-07-12 docs: add Case 8 (Hong Kong Marine Litter Detective) + gap analysis
    - 사례연구: Case 8 홍콩 Marine Litter Detective 편입 (학생 110대·11학교, Arduino Pro Mini + SIM808 2G, 밀랍+티슈 생분해 하우징, MySQL/PHP/Leaflet). 학교 시민과학 최대 선례이자 2G·저사양 MCU·미표준화 반면교사.
    - 왜_공백이_존재했나_한계_반면교사.md (신규): 오픈소스 하천 드리프터가 무브먼트가 못 된 5개 지속 장벽의 정직 분석. Case 8이 이 문서를 링크.
    - DEPENDENCIES.md: Cat/LTE-M/NB-IoT 약자 뜻 + NB-IoT 핸드오버 정확화.
2026-07-12 chore: add .gitattributes to enforce LF (prevent CRLF churn)
    - 모든 텍스트 파일 저장소 LF 고정·체크아웃 LF 통일 → Windows CRLF 변환에 의한 커밋 유령 diff/손실 방지.
    - STL/DXF는 ASCII·LF 저장이라 binary 미지정(자동감지). 재정규화 무변화 확인.
2026-07-13 docs: README에 브랜드 구성 한 줄 추가 (Floatee 활동·SEA:CUT 엔진·프렌들리 플로티 게임)
2026-07-18 fix(firmware): 저전압 가드 추가 — 방전 셀 LTE 송신(2A 피크) 브라운아웃이 버퍼·seq를 날리는 것을 선제 차단
    - BATT_SKIP_TX_V(3.50V): 이하면 GPS fix만 버퍼에 남기고 모뎀 전송을 다음 주기로 미룸
    - BATT_PARK_V(3.30V)+PARK_MULT: 심방전이면 fix도 생략, 장주기 park로 셀 보호
    - readBatteryV: analogReadMilliVolts로 eFuse Vref 교정(raw*3.3/4095의 ADC 비선형·Vref 편차 제거)
    - deepSleepFor(minutes) + reset_reason 로깅(브라운아웃 반복 감지 신호)
    [drifter_a7670_cat1.ino]
2026-07-18 docs(research): 선행사례 연구 §5 — 외해 생존·통신 한계·보드 검증(웹 교차검증 보강)
    - Case 9 Drifter Challenge(ESP32+SIM7000G, 해상 12~36h·~11km) = 우리 보드 동일 계열 실측
    - Case 10 CARTHE(PHA 생분해·GlobalStar·최대 3개월)
    - 외해 생존 종합(생물부착 따개비 2~6주·UV PE 8주) → PET Tier1=주 단위
    - 셀룰러=연안 도구·Swarm 종료 정정·위성 폴백(Iridium/Astrocast/Argos/NTN)·Ganges 이원화 실증
    - A7670 Cat-1 vs SIM7080 판단=현행 유지(L76K 별도 GNSS 결정적)
2026-07-18 docs(hardware): Tier 1.5 솔라 드리프터를 BOM·조립·CAD·DIY·전원문서에 정합
    - BOM: Tier 1.5 섹션(박막 솔라·+$15~25) + 솔라 2형태(고정 Tier-3 / 장기 드리프터) 주석
    - 조립 가이드: 솔라 변형 콜아웃(G5·T7 관문·전력≠커버리지)
    - DIY_DIVERSITY: 티어표 Tier 1.5 행 추가
    - CAD README: 솔라 변형=신규 프린트 없음·CG 보존·폼 재계산 노트
    - ELECTRONICS_POWER §3: Tier 1.5 교차링크(고정 Tier-3와 구분)
2026-07-18 feat(hardware): Tier 1.5 솔라 드리프터 3D/CAD 재설계 — 전문가 군단 통합(major 3 반영)
    - CAD: params.scad 솔라 블록 + solar_variant.scad(viz 전용·프린트 STL 0) + assembly 훅 + assembly_solar.png 렌더
    - ★RF 창 +Z(안테나) 낙하 렌더 검증 완료(필름 아래 240°·위 120° 필름-프리)
    - major A: 저온 충전 컷오프 전 모드 하드웨어 필수(NTC 셀 본딩)·기본 외부 저Iq 선형 차저→배터리단자
    - major B: 비금속 RF투과 기재 하드게이트(a-Si/폴리이미드; 금속기재 금지)·T6 셀장착 검증
    - major C: 신규 프린트 0(Gore-Tex 패치·COTS 컨트롤러·기존 브래킷 지퍼타이)
    - minor: 폼 밀도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
    [assembly.scad, params.scad, solar_variant.scad]
2026-07-18 fix(hardware): Tier 1.5 QA 라운드 개선 — 폼 CAD 연결·assert 게이트·T1 정합·재현성
    QA 군단(4렌즈, 렌더 직접열람) 검수 반영:
    - M1 밀도인지 폼을 CAD 지오메트리에 실제 연결(foam_collar(t)·assembly/export 분기) → 렌더·STL이 27→31mm 실제 반영(기존엔 echo·주석만이라 F2 탈락 크기 출력)
    - M6 비금속 기재 게이트를 assert()로 코드 강제(metal이면 빌드 abort — 산문 아님)·solar_second_cell 질량 실배선
    - M3 Tier 1.5 BOM 표 malformed 수정(Reference orderable 열 신설·실품)
    - M5 T1 정본 정합(24h→30분 침지·Δm≤0.5g, T3 1m→1.5m) TIER1_5·조립
    - M4 T7(셀 장착 자기복원) VER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
    [assembly.scad, export_part.scad, foam_collar.scad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]
2026-07-18 docs(license): 리포 라이선스 자기모순 해소 — 하드웨어 P→S 정정 + 데이터 CC BY 확정
    QA B1 반영(정본 정합):
    - 하드웨어: OPEN_HARDWARE_BOM_global(.md/_ko)의 "CERN-OHL-P recommended"→CERN-OHL-S (정본 LICENSE-hardware.md·params.scad와 정반대였음)
    - 데이터: docs=CC BY-SA 유지 / data=CC BY 4.0로 분리 확정(LICENSE-docs.md·README:7). 리포 ~20곳·모든 레코드가 이미 CC BY, 피어(PlasticPirates)·풀링 커널(K1) 정합. Precious Plastic 카피레프트는 설계·문서 축에 유지
    - m9: README STEP export 주장 정정(OpenSCAD mesh 기반)·Tier 1.5 티어 링크 추가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
2026-07-18 docs(seacut): 남은 minor 마감 — RELIABILITY 폼식 정정(m2) + 변형 레지스트리 실물화(m4)
    QA minor 반영:
    - m2: RELIABILITY §5 밸러스트-폼 트레이드오프식 분모 (1−ρ_foam)→(1−R·ρ_foam)=0.95, ~11.7→11.8 정정(params·VERIFIED_BUILD_TEST comment 동기화). 솔라 밀도인지 6.7과 같은 정확식
    - m4: registry/ 신설 + 참조 시드 2종(_reference-tier1-bottle·_reference-tier1.5-solar) — DIY_DIVERSITY §4.1이 규정만 하던 변형 레지스트리를 실물화. status=reference·evidence 없음(정직). yml 라이선스도 새 결정(docs BY-SA·data BY)에 정합
    [params.scad]
2026-07-18 feat(cad): 솔라 변형 렌더에 충전 컨트롤러·배선·NTC 표시 + 분해 뷰 추가
    - solar_variant.scad: 배선 모듈(패널선 controller→그로밋→필름 / 배터리·NTC선 controller→18650) + NTC 본딩 목업
    - assembly.scad: 컨트롤러=Crimson·패널선=Orange·배터리선=Red·NTC=Gold, 필름 반투명(0.6)으로 내부 가시화. 분해 뷰에서 컨트롤러·NTC를 빼내 명확히(배선은 조립 뷰 전용)
    - assembly_solar_exploded.png 신규(컨트롤러·NTC 부품 위치 한눈에) + assembly_solar.png 갱신
    [assembly.scad, solar_variant.scad]
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2026-07-19 fix(firmware/security): B3 — TLS 인증 공백 명시 + 모뎀 라이브러리 커밋 고정
    보안 리뷰어가 즉시 잡는 두 공백을, 리포 원칙(측정 전 개선 주장 금지)대로
    '테스트된 척' 없이 가시화 + 정확한 교정 훅 제공.
    - TLS-AUTH: 운영 HTTPS의 TinyGsmClientSecure는 CA 미설정 시 서버 인증서를
    검증하지 않아 암호화돼도 MITM에 열림. README에 원인·교정(setCACert+authmode+
    SNI, 하드웨어서 '잘못된 인증서 거부' 확인)을 적고, .ino에 TLS-AUTH 주석과
    주석 처리된 CA 훅(PROD_CA_PEM)을 표시(컴파일 불변, 전처리기·중괄호 균형 확인).
    - 공급망: 'lewisxhe/TinyGSM-fork 사용'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
    [drifter_a7670_cat1.ino]
2026-07-19 feat(hardware): ⑯ 자기복원을 계산으로 — GM/GZ 설계검토 + CI 게이트
    "자기복원 antenna-up(주장)"을 수치 검증으로 격상.
    - hardware/cad/self_righting.py: 수평 부유 원통의 롤 안정 계산(무의존성).
    KB·BM·KG→GM=KB+BM−KG, 복원팔 GZ(φ). ★원형 단면 성질 KM=R(축) 수치확인→
    GM=R−KG로 수렴, 설계규칙 "합성 CG를 병 중심축 아래로". 기본 빌드 GM=+11mm PASS,
    밸러스트 상단(--ballast-z 85)=GM<0 FAIL 정확 판정.
    - hardware/SELF_RIGHTING.md: 모델·원형 단면 결과·정직 한계(소각 이론·균일 단면 가정,
    단일평형 antenna-up과 회수시간은 탱크시험 T4/T7가 확정) 문서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
2026-07-19 fix(ci): OpenSCAD 파싱 게이트를 CSG export로 복구 (최신 OpenSCAD 호환)
    최신 OpenSCAD는 -o 출력 파일의 확장자로 export 포맷을 정하는데 /dev/null은
    확장자가 없어 "Either add a valid suffix..."로 exit 1 → cad-and-registry 실패.
    파싱/컴파일 검증이 목적이므로 -o /tmp/*.csg(렌더 없는 CSG export)로 전환.
    assert(B5 금속기재 하드게이트 등)도 CSG 컴파일 중 실행돼 그대로 유효.
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2026-07-19 fix(ci): CSG→STL — assert 하드게이트는 렌더 단계에서 작동
    CSG export는 렌더를 안 해 assert(B5 금속기재 abort)가 스킵돼 게이트가
    무력화됐다(직전 커밋 부작용). STL 렌더로 전환하면 전체 지오메트리 평가 중
    assert가 실행돼 금속기재가 예전처럼 abort. 확장자 .stl 로 최신 OpenSCAD의
    suffix 요구도 충족.
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2026-07-20 fix: 검수서 치명·고위험 반영 — firmware/BOM 폐기·패널 Vmp/Voc·self_right --solar
    17-에이전트 실습자 검수(치명1·고위험) 조치.
    - ★치명: firmware/BOM.md 최상단 DEPRECATED 배너 — 이 표대로 사면 배포불가+
    발화 동시. SIM7080G(국내 attach 미검증)·TP4056(저온차단 없음=겨울 발화)·
    "주간충전 무한/5분 상시"(허위, 5분은 최다소비 ≈4일). 정본=hardware/BOM.md.
    비파괴(삭제 대신 배너, 이력 보존).
    - hardware/BOM.md 솔라 행: Vmp≈5V/Voc≤6V 명시 — 6V 명목 a-Si의 ~7.5V 개방전압이
    CN3065 입력창(4.4~6V) 초과해 저광량 stall. 데이터시트 확인 지시.
    - self_righti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
2026-07-20 fix: 검수 고위험 반영(2) — 드론강등·장기잔류 SOP·저온컷오프 게이트·인제스트 obs_id
    - 회수·드론(PRELAUNCH): 드론을 Class B "기본수단"→미검증 R&D 옵션으로 강등,
    1차수단=하류 캐치포인트. ★드론 판정 주석(표류=환상·BVLOS 30~90일·다운워시·
    좌초만 조건부). ★2-6 장기잔류(Tier 1.5) 회수 SOP 신설: 최대잔류 상온14/냉수7일
    (=솔라 블랙아웃 시 남은 배터리로 회수 가능한 기한, 에너지최대 아님)·정지24h
    재출동·캐치포인트 상류 지오펜스·온콜·능동회수/Tier1 강등.
    - 저온컷오프(TIER1_5): 스펙에 ★구현 2경로(차저 TS핀 1차+CN3065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
2026-07-20 fix: 검수 문서정합(3) — 솔라 관통부·콜드attach 로그·부유자세 통일
    - 솔라 배선 관통부(조립_가이드 §3-S): "§3-0 그로밋 재사용" 순환참조 제거 —
    §3-0은 겹침 이음이지 배선 그로밋 아님. IP68 케이블 글랜드(캡) 또는 이음부
    배선 포팅+스트레인릴리프로 직접 시공, 관통부 포함 T1 재통과 명시.
    - 콜드 attach 로그(firmware/README): 첫 attach 계측 가이드 신설 — TINY_GSM_DEBUG
    AT에코 + CSQ/등록상태/operator/modeminfo 로그 + 첫 attach 120~180s +
    웨이크내 1~2회 재시도. 무음 실패(안테나·밴드·로밍거부·SIM미개통) 구분.
    - 부유자세(RELIABILITY §2):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
2026-07-20 fix: 캐치포인트 과신 정정 — 진짜 회수 근간은 GPS좌표+닿는곳만(Class A)
    '하류 캐치포인트가 1차수단·물살이 실어다줌'은 과신이었음(사용자 지적).
    그물=점용허가 구조물·모든쓰레기 막아 관리필요·홍수위험, ★조석하구엔 고정
    '하류' 없어 무력(하필 Tier1.5 장기잔류가 값진 하구). 진짜 1차=유닛이 알린
    GPS좌표로 사람이 찾아가 건지기+Class A(닿는곳만). 캐치포인트=좁은 일방수로
    보조. 조석·홍수·복잡수로 회수수단 없으면 Class C=방류금지.
2026-07-20 fix: 솔라 랩 물리 문구 정정 — 자세 고정(윗면 발전·배는 늘 어두움)
    '어느 자세로 뒹굴어도 일부 면 수광'은 부정확(사용자 지적). 자기복원체는
    떠있는 자세가 고정이라 아무면 교대가 아님 — 윗면 호가 늘 하늘, 물속 아랫면은
    발전 못함. 감는 실익=굽은 윗면호가 해 일주·요잉·동요에 계속 수광+기울어도
    일부 유지+분산 저질량(CG 보존). 유효 수확≈물밖 윗부분만(과대계산 금지, G5).
    G5 문구도 '고정면 없음'→'상면 고정·요잉으로 수광호 이동'으로 정밀화.
2026-07-20 feat: G7 솔라 랩 담금 생존 게이트 신설 + G6 오타 수정
    '필름 자체가 몇 주 침지 견디나'가 T1(하우징 밀봉)·G5(수확)와 별개로 어디에도
    없던 명시 게이트라 신설. 완성 유닛 예정기간 담금→①발전 유지 ②가장자리/리드
    물침투 ③부식 확인. '생활방수 표기'만 믿지 말고 담가봐야 함. 방류 게이트에 편입.
    G6 앞 '- -' 마크다운 오타도 수정.
2026-07-26 feat(hardware): GPS 모듈 배선도 — 'Without GPS' 보드 대체 경로
    레퍼런스(With GPS L76K) 품절·고가 시의 정당한 대안을 문서화.
    ★핵심 사실: A7670 모뎀엔 GNSS가 없다 → 'With GPS' 보드도 L76K를 ESP32 UART에
    물려둔 것뿐. 즉 별도 모듈 배선은 꼼수가 아니라 같은 구조.
    - 판매옵션 혼란 정리(Built-in=납땜·External=불명확[판매자 확인]·Without=전무).
    ★LILYGO 공식 예제명이 'ExternalGPS_A7670G_Only'라 이름이 뒤엉킴을 명시.
    - 배선표: 모듈TX→GPIO22(NMEA수신)·RX→GPIO21·9600·Serial2 (우리 펌웨어 핀맵
    그대로라 코드수정 0). TX/RX 교차 함정 명시.
    - ★★전원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
2026-07-26 docs(gps): §7 손익 비교 — 레퍼런스 대비 무엇을 잃고 얻나
    대표 질문('3번이 전원관리 등에서 손실 있나') 검수 결과를 문서화.
    - 전력: ★게이팅만 지키면 슬립 동일. 구형 GPS-only 모듈이면 fix 시간 2배로
    하루 132→168mAh(~19일→~15일, -20%), 멀티GNSS면 그 차이도 대부분 소멸.
    Tier1.5는 태양광이 덮음 → 전력은 결정적 약점 아님.
    ★상시 3.3V 직결 시에만 붕괴(19일→2~3일).
    - ★진짜 손실은 전력이 아니라 납땜점 4개 추가(방수 기기 누수·단선 지점)=최대.
    그 외 질량/CG 재산정·안테나 자유도 하락·미검증(X1~X6).
    - 이 경로 이점도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

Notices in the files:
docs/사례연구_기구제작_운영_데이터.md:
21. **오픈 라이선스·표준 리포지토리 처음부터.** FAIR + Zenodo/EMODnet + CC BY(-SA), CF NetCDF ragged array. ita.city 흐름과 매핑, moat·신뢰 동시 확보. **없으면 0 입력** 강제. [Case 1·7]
